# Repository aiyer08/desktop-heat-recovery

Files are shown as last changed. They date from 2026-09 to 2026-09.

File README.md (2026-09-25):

# Desktop Heat Recovery

Run a computer under a repeatable workload, move some of its cooling-loop heat into an insulated water tank,
and measure **what you gained** (Wh of heat) and **what it cost** (pump electricity, CPU temperature, speed).

```
Loop A (PC):    CPU → CPU water block → heat exchanger → radiator → pump/reservoir → CPU
Loop B (tank):  tank → small pump → heat exchanger → tank
```

## Folder map
| Folder | What's inside |
|---|---|
| `cad/scad/` | Editable OpenSCAD source (change the numbers at the top of each file) |
| `cad/stl/` | Ready-to-print STLs: tank lid, tube-probe clip (print 4), drip tray |
| `cad/build_stl.py` | Rebuilds the STLs in Python if you don't have OpenSCAD |
| `logger/pi_logger.py` | Raspberry Pi: reads DS18B20 probes → CSV |
| `logger/pc_logger.py` | PC: fixed workload + CPU temp/clock/power/throughput → CSV |
| `analysis/analyze.py` | Computes captured heat, pump cost, CPU trade-off, plot, résumé line |
| `data/` | **Simulated** sample data so you can test everything first |
| `docs/index.html` | Project website (works with GitHub Pages) |

## Quick start (test with fake data — no hardware)
```bash
pip install -r logger/requirements.txt
cd analysis
python make_sample_data.py
python analyze.py cooldown --pi ../data/sample_pi_cooldown.csv
python analyze.py run --pi ../data/sample_pi_recovery.csv --pc ../data/sample_pc_recovery.csv \
       --info ../data/sample_run.json --baseline ../data/sample_pc_baseline.csv
```

## Parts list (approx.)
| Item | Notes |
|---|---|
| Custom-loop PC parts | CPU block, pump/reservoir, 240 mm radiator, 10/13 mm soft tube, G1/4 fittings |
| Plate heat exchanger | Small brazed-plate unit with G1/4 or barb ports |
| Tank | 1–3 L food-safe container + foam/foil insulation, printed lid |
| Tank pump | 12 V DC mini pump, **fed from below** by the tank (never run dry) |
| 7 × DS18B20 waterproof probes | tank top, tank bottom, 4 at heat exchanger, 1 room |
| 4.7 kΩ resistor | 1-Wire pull-up between data and 3.3 V |
| Raspberry Pi | any model with GPIO |
| Wall-plug power meter | read kWh at start and end of each run |
| 12 V cartridge heater + PSU | stand-in heat source for the first dry-run tests |

## Probe wiring (all probes share 3 wires)
```
Probe red    → Pi pin 1  (3.3 V)
Probe black  → Pi pin 6  (GND)
Probe yellow → Pi pin 7  (GPIO4)   + 4.7 kΩ resistor from yellow to 3.3 V
```
Enable 1-Wire: `sudo raspi-config` → Interface Options → 1-Wire → reboot.
Run `python3 logger/pi_logger.py --list`, then copy `sensors.example.json` to `sensors.json` and fill in the IDs.

## Test procedure
1. **Baseline** – normal cooling: `python pc_logger.py --minutes 60 --out baseline_01.csv`. Note wall-meter kWh at start/end and room temp.
2. **Dry-run the plumbing** with the PC OFF (or with the 12 V heater). Leak-test for 24 h over paper towel.
3. **Recovery run** – same starting tank temperature every time. Run both loggers together:
   - Pi: `python3 pi_logger.py --out pi_run01.csv`
   - PC: `python pc_logger.py --minutes 60 --out pc_run01.csv`
4. **Cooldown test** – after a run, stop the pumps, log the tank for 2–3 h, then `analyze.py cooldown` gives `loss_k_per_h`.
5. **Fill in `run01.json`** (copy `data/sample_run.json`) and run `analyze.py run`.
6. **Repeat** ≥ 3 runs each and report the mean ± spread.

## The key formula
`heat captured (Wh) ≈ 1.163 × litres × temperature rise (°C)` (+ heat that leaked out, using `k`).
Captured heat is only "energy saved" if you use it for something that would otherwise need heating.

## Safety
Keep the tank and pump lower than and away from the PC, on the drip tray. Leak-test with the PC unplugged.
Never run a pump dry. Use a GFCI/RCD outlet if possible.

## Windows CPU temperature
`psutil` can't read CPU temperature on Windows. Log with HWiNFO or LibreHardwareMonitor at the same interval
and rename its CPU temperature column to `cpu_temp_c`.

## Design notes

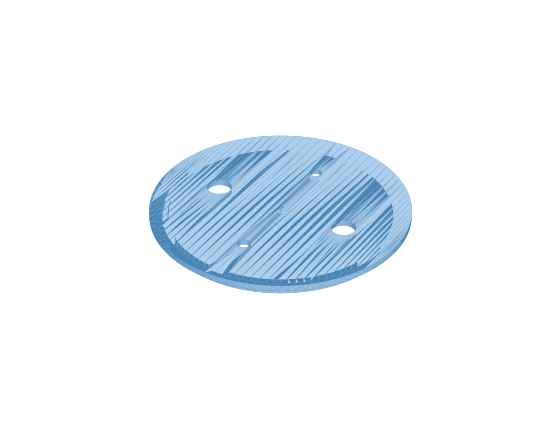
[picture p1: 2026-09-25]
cad/previews/tank_lid.png

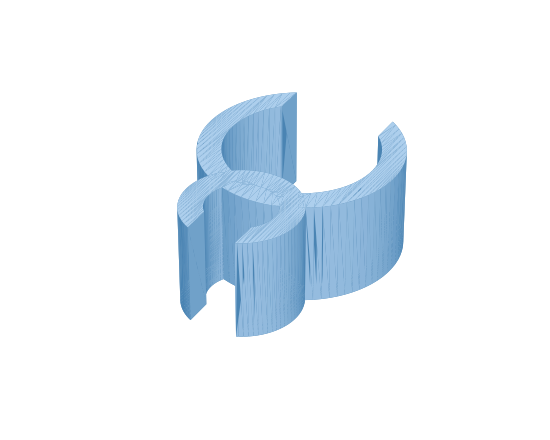
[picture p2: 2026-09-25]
cad/previews/tube_probe_clip.png

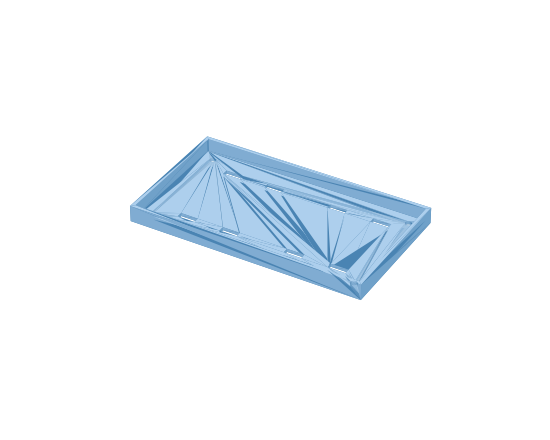
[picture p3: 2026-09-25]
cad/previews/hx_pump_tray.png

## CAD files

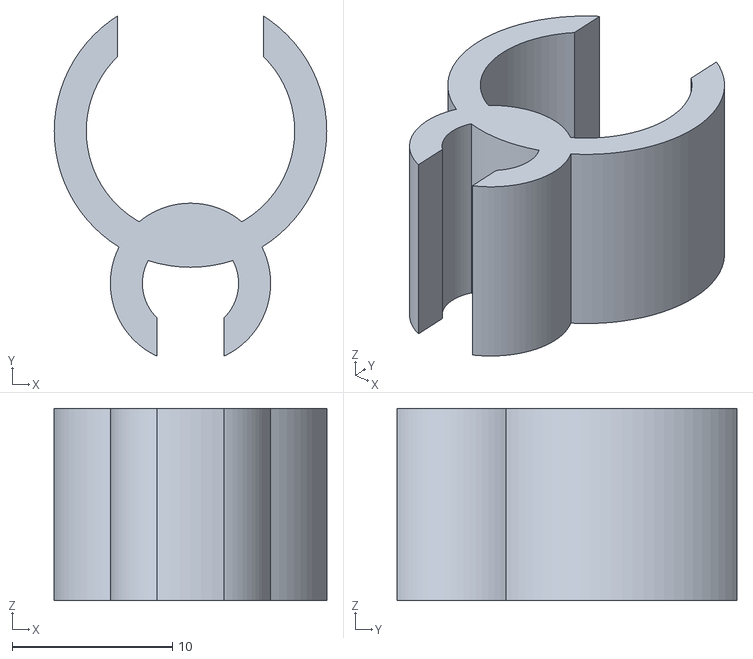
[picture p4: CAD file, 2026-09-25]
cad/stl/tube_probe_clip.stl
17.0 x 21.2 x 12.0

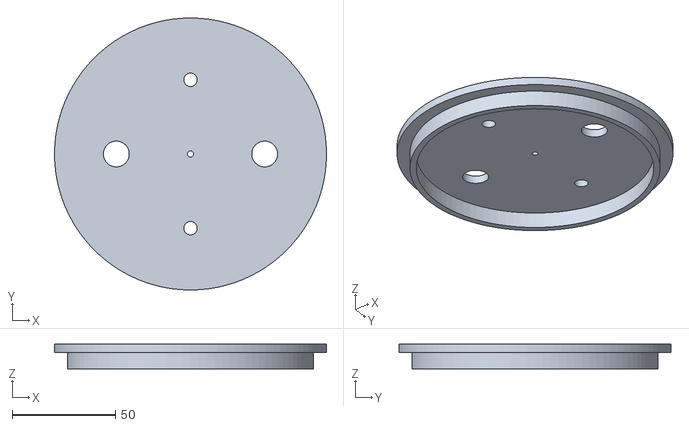
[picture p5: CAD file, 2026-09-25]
cad/stl/tank_lid.stl
132.0 x 132.0 x 12.0

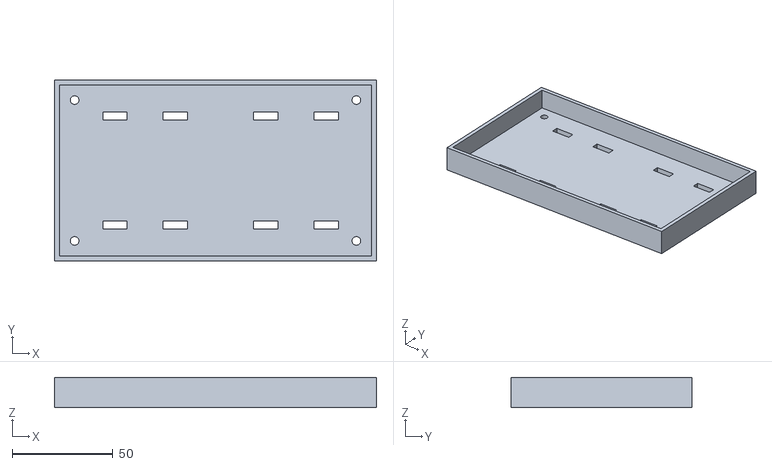
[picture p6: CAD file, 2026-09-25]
cad/stl/hx_pump_tray.stl
160.0 x 90.0 x 15.0

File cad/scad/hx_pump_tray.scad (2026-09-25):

// Drip tray that holds the heat exchanger + tank-loop pump.
// The raised rim catches small leaks so water stays away from the PC.
tray_l   = 160;   // length (mm)
tray_w   = 90;    // width (mm)
floor_t  = 3;     // floor thickness (mm)
rim_h    = 12;    // rim height (mm) – holds ~ tray_l*tray_w*rim_h/1e6 L = ~0.17 L
rim_t    = 2.4;   // rim wall thickness (mm)
slot_l   = 12;    // zip-tie slot length (mm)
slot_w   = 4;     // zip-tie slot width (mm)
screw_d  = 4.3;   // M4 mounting holes
$fn = 48;

difference() {
  cube([tray_l, tray_w, floor_t + rim_h]);
  translate([rim_t, rim_t, floor_t]) cube([tray_l - 2*rim_t, tray_w - 2*rim_t, rim_h + 1]);
  // zip-tie slots: left half = heat exchanger, right half = pump
  for (x = [30, 60, 105, 135]) for (y = [18, tray_w - 18])
    translate([x - slot_l/2, y - slot_w/2, -1]) cube([slot_l, slot_w, floor_t + 2]);
  // corner screw holes
  for (x = [10, tray_l - 10]) for (y = [10, tray_w - 10])
    translate([x, y, -1]) cylinder(d = screw_d, h = floor_t + 2);
}

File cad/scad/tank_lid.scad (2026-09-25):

// Tank lid for the heat-recovery water tank
// Change these numbers to match YOUR container, then export to STL (F6, then F7).
tank_inner_d = 120;   // inside diameter of the tank opening (mm)
lid_t        = 4;     // lid thickness (mm)
overhang     = 6;     // how far the lid sticks out past the opening (mm)
plug_h       = 8;     // depth of the plug that sits inside the opening (mm)
plug_wall    = 3;     // wall thickness of the plug ring (mm)
fit_gap      = 0.4;   // clearance so the plug isn't too tight (mm)
tube_hole_d  = 12.5;  // hole for inlet/outlet (fits a G1/4 bulkhead or 10/13 mm tube)
probe_hole_d = 6.5;   // hole for a 6 mm DS18B20 waterproof probe
vent_d       = 3;     // small vent so the tank isn't sealed
$fn = 96;

difference() {
  union() {
    cylinder(d = tank_inner_d + 2*overhang, h = lid_t);            // top plate
    translate([0,0,-plug_h])
      difference() {                                               // plug ring
        cylinder(d = tank_inner_d - fit_gap, h = plug_h);
        translate([0,0,-1]) cylinder(d = tank_inner_d - fit_gap - 2*plug_wall, h = plug_h + 2);
      }
  }
  r = tank_inner_d * 0.30;
  for (a = [0, 180])  rotate(a)   translate([r,0,-1]) cylinder(d = tube_hole_d,  h = lid_t + 2); // IN / OUT
  for (a = [90, 270]) rotate(a)   translate([r,0,-1]) cylinder(d = probe_hole_d, h = lid_t + 2); // probes top/bottom
  translate([0,0,-1]) cylinder(d = vent_d, h = lid_t + 2);                                    // vent
}

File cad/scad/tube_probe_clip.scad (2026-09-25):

// Snap-on clip that holds a DS18B20 probe tight against a tube.
// Use 4 of these: in/out of the heat exchanger on BOTH loops.
tube_od   = 13;   // outside diameter of your tubing (mm)  (10/13 soft tube = 13)
probe_d   = 6;    // DS18B20 probe diameter (mm)
wall      = 2;    // plastic thickness (mm)
width     = 12;   // clip length along the tube (mm)
open_frac = 0.7;  // opening width as a fraction of diameter (snap-fit)
$fn = 80;

module c_ring(d) {
  difference() {
    cylinder(d = d + 2*wall, h = width);
    translate([0,0,-1]) cylinder(d = d, h = width + 2);
    translate([-d*open_frac/2, 0, -1]) cube([d*open_frac, d, width + 2]);  // snap opening
  }
}
c_ring(tube_od);
// probe ring sits touching the tube wall on the opposite side from the opening
translate([0, -(tube_od/2 + probe_d/2), 0]) rotate(180) c_ring(probe_d);

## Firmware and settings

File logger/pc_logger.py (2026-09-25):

"""
PC-side logger + repeatable workload.

WHAT IT DOES: loads every CPU core with the SAME fixed math task and, every few seconds, records
how much work got done (throughput), CPU temperature, clock speed, and (on Linux/Intel/AMD) CPU power.
WHY: "work done per second" is how you detect thermal throttling — if the heat-recovery loop
makes the CPU hotter and it slows down, throughput drops compared to the baseline.

Usage:
    pip install psutil
    python pc_logger.py --minutes 60 --out baseline_01.csv
    python pc_logger.py --minutes 60 --out recovery_01.csv
Windows note: psutil can't read CPU temperature on Windows. Run LibreHardwareMonitor or HWiNFO
alongside and export its log; the analysis script can merge it (see README).
"""
import argparse, csv, glob, multiprocessing as mp, os, time
from datetime import datetime
import psutil

def worker(counter, stop):
    """Fixed, repeatable job: the same arithmetic forever. Each batch done adds 1 to the counter."""
    x = 0
    while not stop.is_set():
        for i in range(200_000):
            x = (x * 1103515245 + 12345 + i) & 0xFFFFFFFF
        with counter.get_lock():
            counter.value += 1

def cpu_temp():
    try:
        t = psutil.sensors_temperatures()
        for key in ("coretemp", "k10temp", "zenpower", "cpu_thermal", "acpitz"):
            if key in t and t[key]:
                return max(s.current for s in t[key])
    except (AttributeError, OSError):
        pass
    return None

class RAPL:
    """Reads CPU package energy from Linux's RAPL counter (Intel & most modern AMD). Gives watts."""
    def __init__(self):
        p = glob.glob("/sys/class/powercap/intel-rapl:0/energy_uj")
        self.path = p[0] if p else None; self.last = None
    def watts(self):
        if not self.path: return None
        try:
            e, t = int(open(self.path).read()), time.time()
        except PermissionError:
            return None                      # needs sudo on newer kernels
        prev, self.last = self.last, (e, t)
        if not prev or e < prev[0]: return None
        return (e - prev[0]) / 1e6 / (t - prev[1])

def main():
    ap = argparse.ArgumentParser()
    ap.add_argument("--minutes", type=float, default=60)
    ap.add_argument("--interval", type=float, default=5)
    ap.add_argument("--threads", type=int, default=os.cpu_count())
    ap.add_argument("--out", default=f"pc_{datetime.now():%Y%m%d_%H%M%S}.csv")
    a = ap.parse_args()

    counter, stop = mp.Value("q", 0), mp.Event()
    procs = [mp.Process(target=worker, args=(counter, stop), daemon=True) for _ in range(a.threads)]
    for p in procs: p.start()
    rapl, t0, last = RAPL(), time.time(), 0
    rapl.watts()
    print(f"Running workload on {a.threads} threads for {a.minutes} min -> {a.out}")
    with open(a.out, "w", newline="") as f:
        w = csv.writer(f)
        w.writerow(["timestamp", "elapsed_s", "cpu_temp_c", "cpu_freq_mhz", "cpu_util_pct",
                    "cpu_power_w", "batches_per_s"])
        try:
            while time.time() - t0 < a.minutes * 60:
                time.sleep(a.interval)
                done = counter.value; rate = (done - last) / a.interval; last = done
                freq = psutil.cpu_freq()
                row = [datetime.now().isoformat(timespec="seconds"), round(time.time() - t0, 1),
                       cpu_temp(), round(freq.current) if freq else None,
                       psutil.cpu_percent(), rapl.watts(), round(rate, 2)]
                w.writerow(row); f.flush(); print(row)
        except KeyboardInterrupt:
            print("Stopped early.")
    stop.set()
    for p in procs: p.join(timeout=2)

if __name__ == "__main__":
    main()

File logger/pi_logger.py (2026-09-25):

"""
Raspberry Pi temperature logger for the heat-recovery rig.

WHAT IT DOES: every few seconds it reads each DS18B20 probe and appends one row to a CSV file.
WHY: the tank temperature rise is what we turn into "Wh of heat captured", so it needs a
clean, timestamped record.

One-time Pi setup (turns on the 1-Wire bus the probes talk over):
    sudo raspi-config  ->  Interface Options  ->  1-Wire  ->  Enable  ->  reboot
Wiring: probe red -> 3.3V, black -> GND, yellow -> GPIO4, plus a 4.7k resistor between yellow and 3.3V.

Usage:
    python3 pi_logger.py --list                      # show probe IDs so you can label them
    python3 pi_logger.py --out run01.csv             # log until Ctrl+C
    python3 pi_logger.py --simulate --out test.csv   # no hardware? fake data to test the pipeline
"""
import argparse, csv, glob, json, math, os, random, time
from datetime import datetime

W1 = "/sys/bus/w1/devices/28-*/w1_slave"   # every DS18B20 shows up as a folder starting with 28-
HERE = os.path.dirname(os.path.abspath(__file__))

def find_probes():
    return {p.split("/")[-2]: p for p in glob.glob(W1)}

def read_probe(path):
    """Returns °C, or None if the reading failed the checksum (the 'YES' check)."""
    with open(path) as f:
        lines = f.read().strip().splitlines()
    if len(lines) < 2 or not lines[0].endswith("YES"):
        return None
    return int(lines[1].split("t=")[-1]) / 1000.0

def load_names():
    """sensors.json maps probe IDs to human names, e.g. {"28-0123": "tank_top"}."""
    p = os.path.join(HERE, "sensors.json")
    return json.load(open(p)) if os.path.exists(p) else {}

class Simulator:
    """Fake probes that behave roughly like the real rig, so you can test logging + analysis."""
    names = ["tank_top", "tank_bottom", "hx_hot_in", "hx_hot_out", "hx_cold_in", "hx_cold_out", "room"]
    def __init__(self): self.t0 = time.time(); self.tank = 22.0
    def read(self):
        mins = (time.time() - self.t0) / 60
        self.tank = 22 + 12 * (1 - math.exp(-mins / 40))
        base = {"tank_top": self.tank + 0.3, "tank_bottom": self.tank - 0.3, "hx_hot_in": self.tank + 14,
                "hx_hot_out": self.tank + 9, "hx_cold_in": self.tank, "hx_cold_out": self.tank + 3, "room": 22}
        return {k: round(v + random.gauss(0, 0.06), 3) for k, v in base.items()}

def main():
    ap = argparse.ArgumentParser()
    ap.add_argument("--out", default=f"pi_{datetime.now():%Y%m%d_%H%M%S}.csv")
    ap.add_argument("--interval", type=float, default=5.0, help="seconds between readings")
    ap.add_argument("--list", action="store_true")
    ap.add_argument("--simulate", action="store_true")
    a = ap.parse_args()

    if a.simulate:
        sim = Simulator(); cols = sim.names; read_all = sim.read
    else:
        probes, names = find_probes(), load_names()
        if not probes:
            raise SystemExit("No DS18B20 probes found. Is 1-Wire enabled and is the 4.7k resistor fitted?")
        if a.list:
            for pid, path in probes.items():
                print(pid, names.get(pid, "(unnamed)"), read_probe(path), "°C")
            return
        cols = [names.get(pid, pid) for pid in probes]
        def read_all():
            return {names.get(pid, pid): read_probe(path) for pid, path in probes.items()}

    new = not os.path.exists(a.out)
    with open(a.out, "a", newline="") as f:
        w = csv.DictWriter(f, fieldnames=["timestamp", "elapsed_s"] + cols)
        if new: w.writeheader()
        t0 = time.time()
        print(f"Logging to {a.out} every {a.interval}s. Ctrl+C to stop.")
        try:
            while True:
                row = {"timestamp": datetime.now().isoformat(timespec="seconds"),
                       "elapsed_s": round(time.time() - t0, 1), **read_all()}
                w.writerow(row); f.flush()           # flush = save now, so a crash loses nothing
                print(row)
                time.sleep(a.interval)
        except KeyboardInterrupt:
            print("Stopped.")

if __name__ == "__main__":
    main()

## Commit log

2026-09-25 Add printable STL parts
    [hx_pump_tray.stl, tank_lid.stl, tube_probe_clip.stl]
2026-09-25 Add editable OpenSCAD sources
    [hx_pump_tray.scad, tank_lid.scad, tube_probe_clip.scad]
2026-09-25 Add CAD preview images
